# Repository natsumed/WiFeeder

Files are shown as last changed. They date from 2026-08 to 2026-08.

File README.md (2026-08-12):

# WiFeeder v2 — Project README

> **Wireless Automatic Cow Feeding System**  
> NRF24L01+ 2.4 GHz Communication | NUCLEO-L432KC | Raspberry Pi  

> **Status (2026-08-11):** Wiring MVP locked (PCA9685). **NRF VCC = 3.3 V** — Nucleo 5V (~4.8 V) permanently kills PA/LNA (SPI can still look OK). Firmware motor path is I2C PCA9685. Actuator hybrid PCB in [`pcb/`](pcb/). Pi host uses **JSON**. RF over-air still the bring-up gate (need **new** modules after the 5 V damage).

---

## Quick Navigation

| Document | Description |
|---|---|
| [docs/wifeeder-v2-final-plan.md](./docs/wifeeder-v2-final-plan.md) | **Implementation plan** — pins, v1 port, phases, acceptance |
| [ARCHITECTURE.md](./ARCHITECTURE.md) | System architecture, state machines, data flow diagrams |
| [HARDWARE.md](./HARDWARE.md) | Pin mappings, wiring diagrams, power budget |
| [pcb/](./pcb/) | **Actuator hybrid PCB** (KiCad **6.0**) — PCA9685 + bucks on-board; Nucleo/IBT/NRF modules |
| [wiring/](./wiring/) | **Fritzing pack** — bench / no-PCB; `wifeeder-v2.fzz`, GX map |
| [PROTOCOL.md](./PROTOCOL.md) | NRF24L01+ communication protocol specification |
| [SOFTWARE.md](./SOFTWARE.md) | Code architecture, task model, class diagrams |
| [TESTING.md](./TESTING.md) | Test strategy, test cases, validation procedures |
| [DEPLOYMENT.md](./DEPLOYMENT.md) | Build, flash, and deployment instructions |
| [TROUBLESHOOTING.md](./TROUBLESHOOTING.md) | Common problems and solutions |
| [BILL_OF_MATERIALS.md](./BILL_OF_MATERIALS.md) | Complete materials list |

---

## System Overview

```mermaid
graph LR
    CLOUD[" Agpro Cloud"] <-->|"MQTT"| RPI[" Raspberry Pi"]
    RPI <-.->|"NRF24L01+<br/>2.4 GHz"| STM[" NUCLEO-L432KC"]
    STM --> RFID[" RFID Reader"]
    STM --> MOTOR[" Motors (2x)"]
    STM --> HX711[" Load Cell"]
```

WiFeeder v2 is a complete rewrite of the original CAN-bus-based cow feeding system, replacing the problematic wired communication with reliable NRF24L01+ wireless modules.

- **Cow approaches feeder** → RFID tag read
- **Tag sent over NRF24L01+** → Raspberry Pi controller
- **Diet calculation** → Feed command sent back
- **Motors dispense feed** → Encoders verify quantity
- **Consumption reported** → Agpro cloud via MQTT

---

## Repository Structure

```
wifeeder-v2/
├── README.md                          # This file
├── ARCHITECTURE.md                    # System architecture
├── HARDWARE.md                        # Hardware specs
├── PROTOCOL.md                        # Communication protocol
├── SOFTWARE.md                        # Software architecture
├── TESTING.md                         # Test plan
├── DEPLOYMENT.md                      # Deployment guide
├── TROUBLESHOOTING.md                 # Troubleshooting
├── BILL_OF_MATERIALS.md              # Materials list
│
├── stm32/                             # STM32 firmware
│   ├── Core/{Inc,Src}/               # Application code
│   ├── Drivers/                       # HAL & CMSIS
│   ├── Middlewares/                   # FreeRTOS
│   └── Config/                        # RTOS config
│
├── raspberry/                         # RPi host software
│   ├── src/                           # C++ source
│   ├── include/                       # C++ headers
│   ├── config/                        # JSON configs
│   └── tests/                         # GTest tests
│
├── pcb/                               # Actuator hybrid KiCad 8 carrier
├── wiring/                            # Fritzing bench pack
├── docs/                              # Additional docs
├── scripts/                           # Build & deploy
├── tests/                             # Integration tests
└── assets/                            # Images & diagrams
```

---

## Key Differences from v1

| Feature | v1 (CAN) | v2 (NRF24L01+) |
|---|---|---|
| Communication | CAN bus (wired) | NRF24L01+ (wireless) |
| MCU | STM32L486ZGTx | NUCLEO-L432KC |
| Motor Driver | GTK08 | IBT-2 (BTS7960B) |
| Power | Direct 12V | Mini360 DC-DC Buck |
| Protocol | CAN frames (8B) | NRF packets (32B) |
| Database | JSON file (`wifeeder-data.json`) | SQLite (planned) |
| Range | Limited by cable | ~100m wireless |
| Cost per node | ~$15 (CAN parts) | ~$3 (NRF module) |

---

## Quick Start

### Prerequisites

- **Hardware**: NUCLEO-L432KC, NRF24L01+ x2, IBT-2, RFID reader, motors with encoders, Raspberry Pi
- **Software**: STM32CubeIDE, CMake 3.16+, GCC arm-none-eabi, g++ C++20
- **Pi Tools**: spidev / sysfs GPIO, libmosquitto (optional), JSON file DB

### Build STM32 Firmware

```bash
cd stm32
mkdir build && cd build
cmake .. -DCMAKE_TOOLCHAIN_FILE=../cmake/toolchain-arm-none-eabi.cmake
cmake --build . -j$(nproc)
# Flash: Connect Nucleo via USB, drag .bin to virtual drive
```

### Build Raspberry Pi Host

```bash
cd raspberry
mkdir build && cd build
cmake .. -DCMAKE_BUILD_TYPE=Release
cmake --build . -j$(nproc)
# Install: sudo cmake --install .
```

### Configure & Run

```bash
# On Pi:
sudo systemctl enable wifeeder-v2
sudo systemctl start wifeeder-v2

# Monitor:
journalctl -u wifeeder-v2 -f

# Check NRF communication:
sudo candump nrf  # (uses virtual CAN interface to monitor NRF messages)
```

---

## Communication Flow

```mermaid
sequenceDiagram
    participant Cow as 
    participant STM32 as STM32
    participant RPi as RPi
    participant Cloud as  Cloud

    loop Every 5s
        STM32->>RPi: STATUS (heartbeat)
        RPi->>STM32: ACK
    end

    Cow->>STM32: RFID tag read
    STM32->>RPi: RFID_TAG
    RPi->>RPi: Lookup diet
    RPi->>STM32: FEED_CMD (revolutions)
    STM32->>STM32: Dispense feed
    STM32->>RPi: FEED_DONE (actual)
    RPi->>Cloud: Publish via MQTT
```

---

## License

Proprietary — CodinTek © 2024

## Support

For questions or issues, see [TROUBLESHOOTING.md](./TROUBLESHOOTING.md) or contact the development team.

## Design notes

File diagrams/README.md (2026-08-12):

# WiFeeder v2 — Mermaid Diagrams

This directory contains Mermaid `.mmd` files extracted from the project documentation, plus **PLAN-*** diagrams from the implementation plan.

## How to View

### Method 1 — VS Code (Recommended)

1. Open any `.mmd` file
2. VS Code will prompt to install the Mermaid extension — accept it
3. Or press `Ctrl+K V` to open the Mermaid Preview

### Method 2 — Mermaid Live Editor

1. Go to https://mermaid.live/
2. Paste the content of any `.mmd` file
3. See the diagram rendered instantly

### Method 3 — CLI (requires Node.js)

```bash
npm install -g @mermaid-js/mermaid-cli
mmdc -i diagram.mmd -o diagram.png -w 1200
```

## File Index

### Implementation plan (authoritative for pins / port)

| File | Source | Content |
|---|---|---|
| `PLAN-01-system-context.mmd` | docs/wifeeder-v2-final-plan.md | Cloud ↔ Pi ↔ STM32 |
| `PLAN-02-phase-roadmap.mmd` | docs/wifeeder-v2-final-plan.md | Phase gates |
| `PLAN-03-pinmap-l432kc.mmd` | docs/wifeeder-v2-final-plan.md | Locked L432KC pin map |
| `PLAN-04-feed-sequence.mmd` | docs/wifeeder-v2-final-plan.md | RFID → diet → feed → MQTT |
| `PLAN-05-freertos-tasks.mmd` | docs/wifeeder-v2-final-plan.md | Radio / Wifeeder / Cmd / Iwdg |
| `PLAN-06-v1-port-matrix.mmd` | docs/wifeeder-v2-final-plan.md | Port / replace / drop from v1 |
| `PLAN-07-protocol-map.mmd` | docs/wifeeder-v2-final-plan.md | v1 CAN types → v2 NRF types |

### Extracted from docs

| File | Source | Content |
|---|---|---|
| `ARCHITECTURE-01.mmd` … `09` | ARCHITECTURE.md | System overview, flows, topology |
| `HARDWARE-01.mmd` … `09` | HARDWARE.md | Pin maps & wiring (**L432KC-corrected**) |
| `PROTOCOL-01.mmd` … `10` | PROTOCOL.md | Communication protocol |
| `SOFTWARE-01.mmd` … `08` | SOFTWARE.md | Code architecture |
| `TESTING-01.mmd` … `04` | TESTING.md | Test plans |
| `DEPLOYMENT-01.mmd` … `02` | DEPLOYMENT.md | Deployment flows |
| `README-01.mmd` … `02` | README.md | Project overview |
| `TROUBLESHOOTING-01.mmd` … `03` | TROUBLESHOOTING.md | Diagnostics |
| `BILL_OF_MATERIALS-01.mmd` … `03` | BILL_OF_MATERIALS.md | Hardware diagrams |

> **Pin authority:** Prefer `PLAN-03-pinmap-l432kc.mmd` and [`docs/wifeeder-v2-final-plan.md`](../docs/wifeeder-v2-final-plan.md) §2 over any older diagram that cites PB8–PB11, PC0/PC1, TIM3/TIM4, or PA6 as NRF MISO.

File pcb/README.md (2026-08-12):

# WiFeeder actuator carrier (hybrid, spin 1)

KiCad **6.0** project (matches this machine): [`wifeeder-actuator.kicad_pro`](wifeeder-actuator.kicad_pro)

Replaces the Fritzing breadboard, PCA9685 breakout, Mini360, and jumper harness.
Firmware pins are unchanged — see [`../stm32/Core/Inc/board.h`](../stm32/Core/Inc/board.h) and
[`../wiring/CONNECTOR_MAP.md`](../wiring/CONNECTOR_MAP.md).

| On this PCB | Plug-in modules | Off-board |
|---|---|---|
| PCA9685 + passives | NUCLEO-L432KC | Raspberry Pi + NRF |
| Fixed 5 V + 3.3 V bucks | IBT-2 (BTS7960) | PN01007BRKT + GTS06 |
| Enc / I2C pull-ups, fuse, TVS, P-FET | NRF24 + AM1117 (2×4) | 12 V pack |
| Screw / JST connectors | Mini360 **DNP fallback only** | — |

**Do not** chip-down STM32, BTS7960, or nRF24 on this spin.

## Open / regenerate

```bash
# Open in KiCad 6.0 (installed as /usr/bin/kicad)
kicad pcb/wifeeder-actuator.kicad_pro

# After open: PCB editor → B (fill zones) → Inspect → Design Rules Checker
# Schematic: Inspect → Electrical Rules Checker

# Regenerate schematic + placement (no copper — does NOT route)
python3 pcb/tools/generate_project.py
python3 pcb/tools/route_pcb.py      # power + signal routing
python3 pcb/tools/verify_pcb.py     # KiCad connectivity (unconnected must be 0)
python3 pcb/tools/export_fab.py     # zone fill + gerbers
python3 pcb/tools/audit_pcb.py      # pad-to-trace check
```

Fritzing remains the **no-PCB bench** pack under [`../wiring/`](../wiring/).

## Power (read before first apply)

1. No modules seated. Apply 12 V to **TB1**. Measure **TP5V ≈ 5.00 V**, **TP3V3 ≈ 3.30 V**.
2. Seat Nucleo with **USB unplugged** (carrier feeds **3V3 → Nucleo 3V3**).
3. Seat NRF adapter: **VCC is 5 V** (not 3.3 V).
4. Seat IBT-2. Wire **TB2** (12V_SAFE / GND) to IBT **B+ / B−** with short 16 AWG (module has no underside power pins). Motor: IBT **M+/M−** and/or **TB3**.
5. Encoder on **TB4** (5 V VCC, 3.3 V pull-ups on A/B).

Mini360 (`J_MINI`) is **do not populate** unless the AP63203 is omitted and `SJ_MINI` is closed.

## Sheets

| File | Contents |
|---|---|
| `wifeeder-actuator.kicad_sch` | Root / hierarchy |
| `power.kicad_sch` | 12 V protect, 5 V / 3.3 V bucks, Mini360 DNP |
| `mcu.kicad_sch` | Nucleo-32 sockets, NRF, encoder, RFID/HX711 DNP |
| `pca.kicad_sch` | PCA9685 chip-down |
| `ibt.kicad_sch` | IBT-2 logic + power screws |
| `connectors.kicad_sch` | Mechanical notes / mounting |

Pinouts: [`CONNECTORS.md`](CONNECTORS.md).

## Fab

- 2-layer, 1.6 mm, 2 oz Cu preferred, 100×150 mm, ENIG or HASL
- Gerbers: [`fab/`](fab/)
- Keepout: no 12 V under NRF antenna (top-right)

## Bring-up

1. Rails only (above)
2. Nucleo LED blink
3. PCA ACK `0x40`
4. [`../tests/04-motor`](../tests/04-motor/)
5. NRF tests 10 then 09, CH **76**, antennas, ≥10 cm
6. Encoder **2400** counts/rev

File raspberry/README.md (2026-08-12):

# WiFeeder v2 — Raspberry Pi Host

Host controller for WiFeeder v2: NRF24L01+ link to STM32 actuators, diet calculation, JSON database, and MQTT uplink.

Station serial number: **WCN-A100-0001X**

## Features

- 32-byte NRF protocol (`0x01`–`0x08`) with CRC-8 poly `0x07` (matches STM32)
- `nrf_link` API (init/start/stop/sendto/recv) modeled on v1 `walink`
- LINEAR_FORCED diet engine ported from v1 `diet.cpp`
- JSON file database (`wifeeder-data.json`) with mutex
- MQTT via libmosquittopp (optional stub without it)
- Desktop Linux build uses NRF stub (logs packets, no SPI)

## Dependencies

**Required**

- CMake ≥ 3.16, C++17 compiler, pthread

**Optional**

- `jsoncpp` — used when found; otherwise embedded `min_json`
- `libmosquittopp` — real MQTT; otherwise stub logs to stdout
- `libgtest-dev` — GoogleTest runner for `test_diet`

On Raspberry Pi OS:

```bash
sudo apt update
sudo apt install -y cmake g++ libjsoncpp-dev libmosquittopp-dev
```

## Build

### Desktop (stub NRF, diet unit tests)

```bash
cd raspberry
cmake -B build -DWIFEEDER_BUILD_TESTS=ON
cmake --build build
ctest --test-dir build --output-on-failure
```

### Raspberry Pi (SPI + GPIO)

Enable SPI and reboot:

```bash
sudo raspi-config   # Interface Options → SPI → Enable
# or:
echo dtparam=spi=on | sudo tee -a /boot/config.txt
sudo reboot
```

Build with Pi defines:

```bash
cd raspberry
cmake -B build -DRASPBERRY_PI=ON
cmake --build build
```

## Run

Copy seed data (first run):

```bash
cp config/wifeeder-data.json ./wifeeder-data.json
# or set WIFEEDER_DATA=/etc/wifeeder-data.json
```

Start host:

```bash
./build/wifeeder_host
```

Environment variables:

| Variable | Default | Description |
|---|---|---|
| `WIFEEDER_DATA` | `./wifeeder-data.json` | Animal/diet JSON database path |

## Wiring (NRF24L01+ → Raspberry Pi)

| NRF pin | Pi connection |
|---|---|
| VCC | 3.3V (use adapter with regulator) |
| GND | GND |
| CE | GPIO25 (BCM) |
| CSN | SPI0 CE0 |
| SCK | SCLK (pin 23) |
| MOSI | MOSI (pin 19) |
| MISO | MISO (pin 21) |
| IRQ | not connected |

SPI device: `/dev/spidev0.0`

Radio settings match STM32 and `PROTOCOL.md`:

- Channel 76 (2.476 GHz)
- 1 Mbps, 32-byte payload
- Address `0xE7E7E7E7E7`

## Thread model

1. **NRF RX thread** (`nrf_link`) — receives packets, auto-ACK
2. **Feed thread** — `RFID_TAG` → diet `get_portion` → `FEED_CMD`; `FEED_DONE` → log + MQTT
3. **Status thread** — `STATUS` heartbeat + 5 min offline detection
4. **Daily reset thread** — ~23:50 daily_reset for all animals

## Message flow

See [PROTOCOL.md](../PROTOCOL.md) and [docs/wifeeder-v2-final-plan.md](../docs/wifeeder-v2-final-plan.md).

```
STM32 --RFID_TAG(0x02)--> Host --lookup DB--> diet.get_portion()
Host --FEED_CMD(0x03)--> STM32 --dispense--> FEED_DONE(0x04) --> Host log + MQTT
STM32 --STATUS(0x01)--> Host (every 5s heartbeat)
```

## Unit tests

```bash
./build/test_diet
```

Tests cover portion calculation, grams↔revs conversion (16 rev calibration reference), and `daily_reset` without hardware.

## License

Portions derived from WiFeeder v1 (CodinTek / Mohamed HNEZLI).

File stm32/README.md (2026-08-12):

# STM32 firmware (NUCLEO-L432KC)

Production firmware entry: `Core/Src/main.c` → `wifeeder_init()` / `wifeeder_poll()`.

## Drivers

| Module | Role |
|---|---|
| `nrf24l01` | Bit-bang SPI (PA4 CSN, PB1 MISO) |
| `protocol` / `crc8` | 32-byte NRF packets |
| `rfid` | USART2 RX PA3, `$A0112OKD` frames |
| `motor` | IBT-2 TIM1/TIM16 PWM |
| `encoder` | TIM2 PA0/PA1 |
| `hx711` | PB4/PB5 |
| `flash_int` | Device ID (RAM + flash read) |
| `wifeeder` | Feed loop (STATUS / RFID / FEED_CMD / FEED_DONE) |

FreeRTOS sources are vendored under `Middlewares/Third_Party/FreeRTOS/` (task split later).

## Build

```bash
docker run --rm --user root \
  -v "$PWD:/workspace" -v /home/luceor/Desktop/wifeeder:/wifeeder \
  wifeeder-dev bash -c '
  export PATH=/opt/arm-gcc/bin:$PATH
  cd /workspace/stm32 && mkdir -p build_prod && cd build_prod
  cmake .. -DCMAKE_TOOLCHAIN_FILE=/wifeeder/cmake/toolchain-arm-none-eabi.cmake
  cmake --build . -j$(nproc)
'

# Flash
cp build_prod/wifeeder_v2_mcu.bin /media/$USER/NODE_L432KC/
```

Hardware bring-up tests: see [`../tests/README.md`](../tests/README.md).

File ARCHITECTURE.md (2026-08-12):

# WiFeeder v2 — Architecture Overview

> **Version**: 2.0.0  
> **Communication**: NRF24L01+ 2.4 GHz Wireless  
> **MCU**: STM32 NUCLEO-L432KC  
> **Host**: Raspberry Pi 3B+/4  

---

## Table of Contents

1. [System Overview](#system-overview)
2. [Component Architecture](#component-architecture)
3. [Data Flow](#data-flow)
4. [Network Topology](#network-topology)
5. [Power Architecture](#power-architecture)
6. [State Machines](#state-machines)
7. [Directory Structure](#directory-structure)

---

## System Overview

```mermaid
graph TB
    subgraph Cloud[" Agpro Cloud"]
        MQTT_BROKER["MQTT Broker<br/>Cloud Backend"]
        WEB_DASH["Web Dashboard<br/>Farmer Interface"]
    end

    subgraph RPi[" Raspberry Pi Controller"]
        MQTT_CLIENT["MQTT Client<br/>(Mosquitto)"]
        DIET_ENGINE["Diet Engine<br/>(C++20)"]
        DB["SQLite<br/>Database"]
        WEB_SRV["Web Server<br/>(Optional)"]
        NRF_RPI["NRF24L01+<br/>SPI0 Module"]

        MQTT_CLIENT <--> |"JSON/TLS"| MQTT_BROKER
        MQTT_CLIENT --> DIET_ENGINE
        DIET_ENGINE --> DB
        DIET_ENGINE --> NRF_RPI
        WEB_SRV --> DB
    end

    subgraph STM32[" NUCLEO-L432KC Actuator"]
        NRF_STM32["NRF24L01+<br/>SPI1 Module"]
        MAIN_LOOP["Main Control<br/>Loop"]
        RFID["RFID Reader<br/>125kHz/EM"]
        MOTOR["IBT-2 Motor<br/>Driver"]
        ENCODER["Quadrature<br/>Encoders"]
        HX711["HX711 Load<br/>Cell (Opt.)"]
        CLI["Debug CLI<br/>UART2"]

        NRF_STM32 --> MAIN_LOOP
        MAIN_LOOP --> RFID
        MAIN_LOOP --> MOTOR
        MAIN_LOOP --> ENCODER
        MAIN_LOOP --> HX711
        MAIN_LOOP --> CLI
    end

    NRF_RPI <-.-> |"2.4GHz"| NRF_STM32
    POWER[" 12V Battery<br/>+ Mini360 Buck"] --> STM32

    style Cloud fill:#e1f5fe,stroke:#01579b
    style RPi fill:#e8f5e9,stroke:#1b5e20
    style STM32 fill:#fff3e0,stroke:#e65100
    style POWER fill:#fce4ec,stroke:#880e4f
```

---

## Component Architecture

```mermaid
graph LR
    subgraph Pi["Raspberry Pi"]
        direction TB
        A1["NRF24L01+ Driver<br/>(C++)"] --> A2["Protocol Layer<br/>(msg pack/unpack)"]
        A2 --> A3["Message Router"]
        A3 --> A4["Diet Engine"]
        A3 --> A5["MQTT Client"]
        A4 --> A6["SQLite DB"]
        A5 --> A7["Mosquitto"]
    end

    subgraph STM32["NUCLEO-L432KC"]
        direction TB
        B1["NRF24L01+ Driver<br/>(C)"]
        B1 --> B2["Protocol Layer<br/>(msg pack/unpack)"]
        B2 --> B3["Main Task<br/>(FreeRTOS)"]
        B3 --> B4["RFID Task"]
        B3 --> B5["Motor Task"]
        B3 --> B6["Sensor Task"]
        B3 --> B7["Watchdog Task"]
        B4 --> B8["UART2"]
        B5 --> B9["PWM + GPIO"]
        B6 --> B10["HX711 SPI"]
    end

    A1 <-.-> |"2.4 GHz"| B1
```

---

## Data Flow

### End-to-End Feeding Cycle

```mermaid
sequenceDiagram
    participant Cow as  Cow
    participant RFID as RFID Reader
    participant STM32 as STM32 MCU
    participant NRF_S as NRF24L01 (STM)
    participant NRF_P as NRF24L01 (RPi)
    participant RPi as Raspberry Pi
    participant DB as SQLite DB
    participant MQTT as Agpro Cloud

    Cow->>RFID: Approaches feeder
    RFID->>STM32: Tag detected (125kHz)
    STM32->>NRF_S: Send RFID_TAG (msg ID=0x02)
    NRF_S->>NRF_P: 2.4GHz packet
    NRF_P->>RPi: RFID_TAG received
    RPi->>DB: Lookup animal (RFID)
    DB->>RPi: Diet data found
    RPi->>RPi: Calculate portion
    RPi->>NRF_P: Send FEED_CMD (msg ID=0x03)
    NRF_P->>NRF_S: 2.4GHz packet
    NRF_S->>STM32: FEED_CMD received
    STM32->>STM32: Start motors + encoders
    Note over STM32: Dispensing feed...
    STM32->>NRF_S: Send FEED_DONE (msg ID=0x04)
    NRF_S->>NRF_P: 2.4GHz packet
    NRF_P->>RPi: FEED_DONE received
    RPi->>DB: Update consumption
    RPi->>MQTT: Publish feed event
    MQTT->>RPi: Acknowledge
```

### Heartbeat & Status Flow

```mermaid
sequenceDiagram
    participant STM32 as STM32 MCU
    participant NRF_S as NRF24L01 (STM)
    participant NRF_P as NRF24L01 (RPi)
    participant RPi as Raspberry Pi

    loop Every 5 seconds
        STM32->>NRF_S: Send STATUS (msg ID=0x01)
        NRF_S->>NRF_P: 2.4GHz packet + auto-ACK
        NRF_P->>RPi: STATUS received
        RPi->>NRF_P: Send ACK (msg ID=0x07)
        NRF_P->>NRF_S: 2.4GHz packet + auto-ACK
        NRF_S->>STM32: ACK received
        Note over STM32: Update connection status
    end
```

---

## Network Topology

```mermaid
graph TB
    subgraph Farm[" Farm Layout"]
        subgraph Station1["Station 1"]
            RPi1["Raspberry Pi<br/>Controller #1"]
            STM1_1["Actuator #1<br/>NUCLEO-L432KC"]
            STM1_2["Actuator #2<br/>NUCLEO-L432KC"]
            STM1_3["Actuator #3<br/>NUCLEO-L432KC"]
            RPi1 <-.-> |"NRF24L01+"| STM1_1
            RPi1 <-.-> |"NRF24L01+"| STM1_2
            RPi1 <-.-> |"NRF24L01+"| STM1_3
        end

        subgraph Station2["Station 2"]
            RPi2["Raspberry Pi<br/>Controller #2"]
            STM2_1["Actuator #1<br/>NUCLEO-L432KC"]
            STM2_2["Actuator #2<br/>NUCLEO-L432KC"]
            RPi2 <-.-> |"NRF24L01+"| STM2_1
            RPi2 <-.-> |"NRF24L01+"| STM2_2
        end
    end

    RPi1 --> |"MQTT"| Cloud[" Agpro Cloud"]
    RPi2 --> |"MQTT"| Cloud
```

---

## Power Architecture

```mermaid
graph TB
    BAT[" 12V Battery<br/>or Adapter"] -->|"12V DC"| IBT["IBT-2 Motor Driver<br/>(5-27V tolerant)"]
    BAT -->|"12V DC"| MINI["Mini360 DC-DC<br/>Buck Converter"]
    MINI -->|"3.3V / 3A"| STM32["NUCLEO-L432KC<br/>(3.3V)"]
    MINI -->|"3.3V / 3A"| NRF["NRF24L01+ Module<br/>(3.3V max)"]
    MINI -->|"3.3V / 3A"| RFID_READER["RFID Reader<br/>(3.3V/5V)"]
    IBT -->|"12V PWM"| MOTOR1["Motor 1<br/>DC Brushed"]
    IBT -->|"12V PWM"| MOTOR2["Motor 2<br/>DC Brushed"]
    IBT -->|"5V out"| ENCODER["Encoder<br/>Power"]
    STM32 -->|"5V USB"| USB["USB Debug<br/>Serial Console"]

    style BAT fill:#fce4ec,stroke:#880e4f
    style MINI fill:#e8eaf6,stroke:#283593
    style IBT fill:#fff3e0,stroke:#e65100
    style STM32 fill:#e8f5e9,stroke:#1b5e20
```

---

## STM32 State Machine

```mermaid
stateDiagram-v2
    [*] --> INIT: Power On
    INIT --> CONFIG_READ: Boot
    CONFIG_READ --> RADIO_INIT: Read config
    RADIO_INIT --> IDLE: NRF24L01+ ready

    IDLE --> HEARTBEAT: Timer (5s)
    HEARTBEAT --> WAIT_ACK: Send STATUS
    WAIT_ACK --> IDLE: ACK received
    WAIT_ACK --> RETRY: No ACK (3 retries)
    RETRY --> IDLE: After retry
    RETRY --> ERROR: After max retries
    ERROR --> IDLE: Reconnect

    IDLE --> TAG_READ: RFID detected
    TAG_READ --> SEND_TAG: Tag valid
    SEND_TAG --> WAIT_CMD: RFID_TAG sent

    WAIT_CMD --> START_FEED: FEED_CMD received
    WAIT_CMD --> IDLE: Timeout (no command)
    START_FEED --> FEEDING: Motors running
    FEEDING --> FEED_DONE: Encoders done
    FEED_DONE --> IDLE: FEED_DONE sent

    IDLE --> WEIGHING: Weight requested
    WEIGHING --> IDLE: WEIGHT sent
```

---

## Message Routing (Raspberry Pi)

```mermaid
stateDiagram-v2
    [*] --> LISTENING: NRF24L01+ initialized

    LISTENING --> PARSE: Packet received
    PARSE --> CRC_CHECK: Parse header
    CRC_CHECK --> ROUTE: CRC valid
    CRC_CHECK --> LISTENING: CRC invalid (discard)

    ROUTE --> STATUS_HANDLER: MsgType=0x01
    ROUTE --> RFID_HANDLER: MsgType=0x02
    ROUTE --> FEEDBACK_HANDLER: MsgType=0x04
    ROUTE --> WEIGHT_HANDLER: MsgType=0x05
    ROUTE --> ERROR_HANDLER: MsgType=0x08

    STATUS_HANDLER --> UPDATE_HEARTBEAT: Update timestamp
    UPDATE_HEARTBEAT --> SEND_ACK: Send ACK (0x07)
    SEND_ACK --> LISTENING

    RFID_HANDLER --> LOOKUP_DB: Lookup animal
    LOOKUP_DB --> CALC_PORTION: Animal found
    LOOKUP_DB --> LISTENING: Unknown animal
    CALC_PORTION --> SEND_CMD: Send FEED_CMD (0x03)
    SEND_CMD --> LISTENING

    FEEDBACK_HANDLER --> UPDATE_DB: Update consumption
    UPDATE_DB --> PUBLISH_MQTT: Publish to cloud
    PUBLISH_MQTT --> LISTENING

    WEIGHT_HANDLER --> STORE_WEIGHT: Store in DB
    STORE_WEIGHT --> LISTENING

    ERROR_HANDLER --> LOG_ERROR: Log to syslog
    LOG_ERROR --> LISTENING
```

---

## Directory Structure

```
wifeeder-v2/
├── README.md                          # Project overview
├── ARCHITECTURE.md                    # This file
├── HARDWARE.md                        # Hardware specs & wiring
├── PROTOCOL.md                        # NRF24L01+ protocol
├── SOFTWARE.md                        # Software architecture
├── TESTING.md                         # Test plan
├── DEPLOYMENT.md                      # Deployment guide
├── TROUBLESHOOTING.md                 # Common issues
├── BILL_OF_MATERIALS.md              # Materials list
│
├── stm32/                             # STM32 firmware
│   ├── Core/
│   │   ├── Inc/                       # Headers
│   │   └── Src/                       # Source
│   ├── Drivers/                       # HAL & CMSIS
│   ├── Middlewares/                   # FreeRTOS
│   └── Config/                        # FreeRTOS config
│
├── raspberry/                         # Raspberry Pi controller
│   ├── src/                           # C++ source
│   ├── include/                       # C++ headers
│   ├── config/                        # JSON configs
│   └── tests/                         # GTest tests
│
├── docs/                              # Additional docs
├── scripts/                           # Build & deploy scripts
├── tests/                             # Integration tests
│   ├── unit/                          # Unit tests
│   ├── integration/                   # Integration tests
│   └── system/                        # System tests
└── assets/                            # Images & diagrams
```

---

## Key Design Decisions

| Decision | Rationale |
|---|---|
| NRF24L01+ over CAN | Eliminates wiring issues; cheaper modules |
| NUCLEO-L432KC over L486 | Smaller, cheaper, sufficient peripherals |
| IBT-2 over GTK08 | BTS7960B more robust; better current handling |
| Mini360 buck converter | Efficient 12V→3.3V; adjustable; 3A capacity |
| FreeRTOS (kept) | Real-time motor/encoder control needs |
| SQLite (new on RPi) | Better structured queries vs JSON file |
| 1 Mbps NRF data rate | Best balance of range/speed |

---

## Comparison: v1 vs v2

```mermaid
graph LR
    subgraph V1["v1 (CAN Bus)"]
        direction TB
        C1[" CAN bus wiring<br/>problems for years"]
        C2[" Termination<br/>issues"]
        C3[" Wired connections<br/>limit placement"]
        C4[" Complex<br/>debugging"]
    end

    subgraph V2["v2 (NRF24L01+)"]
        direction TB
        D1[" No wiring<br/>wireless comms"]
        D2[" Auto-retry<br/>reliable delivery"]
        D3[" Flexible<br/>actuator placement"]
        D4[" Simple SPI<br/>easy to debug"]
    end

    V1 --> V2
    style V1 fill:#ffcdd2,stroke:#c62828
    style V2 fill:#c8e6c9,stroke:#2e7d32
```

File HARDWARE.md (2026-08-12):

# WiFeeder v2 — Hardware Specifications & Wiring

> **MCU**: NUCLEO-L432KC (STM32L432KCU6, UFQFPN32)  
> **Motor Driver**: IBT-2 (BTS7960B) via **PCA9685** PWM  
> **Power**: Mini360 DC-DC Buck Converter  
> **Wireless**: NRF24L01+ 2.4 GHz (bit-bang SPI)  
> **Authority**: [`wiring/CONNECTOR_MAP.md`](wiring/CONNECTOR_MAP.md) + [`stm32/Core/Inc/board.h`](stm32/Core/Inc/board.h)

**Package limits:** No PB8–PB11, PC0–PC13, TIM3, or TIM4. LED = **PB3**. **PA6 shorted** — NRF MISO = **PB1**. **One jumper per Nucleo pin**. Bench logic power is **Nucleo USB** (3V3→X, 5V→Z). **Do not** feed Mini360 OUT into Nucleo 3V3 until the pot is **3.30 V**. **NRF VCC = 3.3 V** (never Nucleo 5V).

---

## 1. NUCLEO-L432KC Pin Allocation (MVP)

Diagram: [`diagrams/HARDWARE-01.mmd`](diagrams/HARDWARE-01.mmd).

| Pin | Mode | Function | Connected To |
|-----|---|---|---|
| PA0 | AF1 TIM2_CH1 | Encoder 1A | Enc **green** → BB col 40 |
| PA1 | AF1 TIM2_CH2 | Encoder 1B | Enc **white** → BB col 41 |
| PA2 | AF8 LPUART1 | Debug VCP | ST-Link |
| PA3 | USART2_RX | RFID (deferred) | — |
| PA4 | GPIO Out | NRF CSN | NRF CSN |
| PA5 | GPIO Out | NRF SCK | NRF SCK |
| PA6 | — | **Do not use** | Shorted |
| PA7 | GPIO Out | NRF MOSI | NRF MOSI |
| PA8 / PA9 | — | Free (legacy TIM1) | — |
| PB0 | GPIO Out | NRF CE | NRF CE |
| PB1 | GPIO In PU | NRF MISO | NRF MISO |
| PB3 | GPIO Out | LED | LD3 |
| PB4 / PB5 | — | HX711 (deferred) | — |
| **PB6** | I2C SCL | **PCA9685 SCL** | PCA SCL (D5) |
| **PB7** | I2C SDA | **PCA9685 SDA** | PCA SDA (D4) |

**MVP:** PCA9685 + 1 motor + Enc1 (600 P/R) + NRF + LED. RFID / HX711 / Motor2 deferred.

### board.h ↔ wiring checklist

| `board.h` | Wiring |
|---|---|
| `BOARD_NRF_*` | PA5/7, PB1, PA4, PB0 |
| `BOARD_I2C_SCL/SDA` | PB6 / PB7 |
| `BOARD_PCA_CH_RPWM/LPWM` | PWM0 / PWM1 |
| `BOARD_ENCODER_PPR` | **600** |
| `BOARD_ENCODER_COUNTS_PER_REV` | **2400** (TIM2 ×4) |

---

## 2. NRF24L01+ Wiring

STM: PA5 SCK, PB1 MISO, PA7 MOSI, PA4 CSN, PB0 CE. **VCC = 3.3 V** (Buck / BB X). Channel **76**.

Pi: SPI0 + GPIO25 CE; **VCC = pin 1 (3.3 V)**.

**Never** put Nucleo/Pi **5 V** on module VCC. That is ~4.8 V; abs max is 3.6 V. It destroys PA/LNA while SPI still looks healthy.

---

## 3. Motor path (PCA9685 → IBT-2)

```mermaid
graph TB
    subgraph PCA["PCA9685"]
        PWM0["PWM0"]
        PWM1["PWM1"]
    end
    subgraph IBT["IBT-2 Motor1"]
        RPWM["RPWM"]
        LPWM["LPWM"]
        EN["R_EN/L_EN → Buck 3V3"]
        MOUT["M+/M- → GX-2 → Motor"]
    end
    PWM0 --> RPWM
    PWM1 --> LPWM
```

- OE → Buck GND (outputs enabled)
- Forward: RPWM=PWM, LPWM=0 · Reverse: RPWM=0, LPWM=PWM
- PCA PWM ~1 kHz (IBT-tolerant)
- Legacy TIM1/TIM16 on PA8/PB6 **retired** for MVP

Fritzing: [`wiring/blocks/03-motor.fzz`](wiring/blocks/03-motor.fzz)

---

## 4. Encoder Wiring

**GTS06-OC-RA600A-2M** (600 P/R, NPN OC) as a **factory 4-wire assembly** (encoder + cable + plug). Do not wire a separate GX-4 and encoder body.

Pigtail is **2× red + 2× black** — color is **not** VCC/GND/A/B. Use molded pin numbers + the meter procedure in [`wiring/CONNECTOR_MAP.md`](wiring/CONNECTOR_MAP.md). Then: VCC → BB **Z**, GND → **Y**, A → col **40** / PA0, B → col **41** / PA1.

Pull-ups **4.7 kΩ on A/B → 3V3** (not 5 V; not stacked on Nucleo A0/A1). TIM2 ×4 → **2400 counts/rev**. Swap A/B if direction is inverted.

---

## 5. RFID / HX711

Deferred in MVP Fritzing. Drivers exist; gated with `WIFEEDER_MVP` in firmware. Pins reserved: PA3 RFID, PB4/PB5 HX711.

---

## 6. Complete Wiring

**Production path:** hybrid carrier PCB — [`pcb/README.md`](pcb/README.md), pinouts [`pcb/CONNECTORS.md`](pcb/CONNECTORS.md).  
On-board: PCA9685, fixed 5 V / 3.3 V bucks, fuse, TVS, P-FET, pull-ups. Modules: Nucleo-32, IBT-2, NRF+AM1117.  
**Bench / no-PCB:** [`wiring/wifeeder-v2.fzz`](wiring/wifeeder-v2.fzz) · blocks in [`wiring/blocks/`](wiring/blocks/).

```mermaid
graph TB
    BAT["12V Battery"] -->|"12V fuse P-FET"| IBT["IBT-2"]
    BAT -->|"12V Mini360 IN only"| BUCK["Mini360 — OUT off X until 3.30V"]
    USB["Nucleo USB"] -->|"3V3 → X"| STM32["NUCLEO-L432KC"]
    USB -->|"3V3 → X"| PCA["PCA9685"]
    STM32 -->|"I2C PB6/PB7"| PCA
    PCA -->|"PWM0/1"| IBT
    USB -->|"3V3 → X"| NRF["NRF VCC"]
    USB -->|"5V → Z"| IBT
    USB -->|"5V → Z"| ENC1["Enc 4-wire"]
    IBT -->|"GX-2"| MOTOR1["PN01007BRKT"]
    ENC1 -->|"A / B after meter ID"| STM32
    NRF <-.->|"CH76"| NRF_PI["NRF on Pi"]
```

---

## 7. Power Budget

| Component | Voltage | Notes |
|---|---|---|
| Nucleo | 3.3V | Carrier AP63203 (USB unplugged) |
| PCA9685 | 3.3V | On-carrier |
| NRF | **3.3V** | Buck / BB X — never Nucleo 5V |
| IBT logic | 5V | Carrier 5 V rail |
| Motor | 12V | Battery via fuse / P-FET → IBT B+ |

---

## 8. NUCLEO-L432KC Key Specs

| Parameter | Value |
|---|---|
| Core | Cortex-M4 |
| Flash / SRAM | 256 KB / 64 KB |
| Timers (MVP) | TIM2 Enc1; SysTick |
| PWM | External PCA9685 |
| Debug | SWD + ST-Link |

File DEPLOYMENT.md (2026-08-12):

# WiFeeder v2 — Deployment Guide

---

## Table of Contents

1. [STM32 Firmware Deployment](#stm32-firmware-deployment)
2. [Raspberry Pi Deployment](#raspberry-pi-deployment)
3. [NRF24L01+ Setup](#nrf24l01-setup)
4. [Systemd Service Configuration](#systemd-service-configuration)
5. [MQTT Configuration](#mqtt-configuration)
6. [Docker Deployment (Optional)](#docker-deployment-optional)

---

## 1. STM32 Firmware Deployment

### 1.1 Prerequisites

```bash
# Install ARM GCC toolchain
sudo apt update
sudo apt install gcc-arm-none-eabi binutils-arm-none-eabi
```

### 1.2 Build & Flash

```mermaid
sequenceDiagram
    participant Dev as Developer PC
    participant STM32 as NUCLEO-L432KC

    Dev->>Dev: Clone repository
    Dev->>Dev: cd stm32 && mkdir build && cd build
    Dev->>Dev: cmake .. -DTOOLCHAIN=arm-none-eabi
    Dev->>Dev: cmake --build . -j$(nproc)
    Dev->>Dev: Check build output
    Note over Dev: wifeeder_mcu.bin created
    Dev->>STM32: Copy .bin to NUCLEO drive
    Dev->>STM32: Press RESET button
    STM32->>STM32: Boot new firmware
    Dev->>STM32: Open serial terminal (115200 baud)
    Note over Dev,STM32: Verify boot messages
```

### 1.3 CLI Configuration

After flashing, configure the actuator via serial terminal:

```text
# Connect to NUCLEO serial at 115200 baud
screen /dev/ttyACM0 115200

# Set device ID (1-254)
flash-device-id 1

# Set machine type
flash-device-type 3

# Verify
get-id
get-type

# Set NRF channel (optional, default 76)
set-nrf-channel 76

# Reset to apply
reset
```

---

## 2. Raspberry Pi Deployment

### 2.1 OS Setup

```bash
# On Raspberry Pi (fresh Raspbian/Ubuntu)
sudo apt update && sudo apt upgrade -y

# Enable SPI interface
sudo raspi-config
# → Interface Options → SPI → Enable

# Install dependencies
sudo apt install -y \
    cmake \
    build-essential \
    g++ \
    libmosquitto-dev \
    libsqlite3-dev \
    libwiringpi-dev \
    git

# Enable SPI
sudo sed -i 's/#dtparam=spi=on/dtparam=spi=on/' /boot/config.txt
sudo reboot
```

### 2.2 Build Application

```bash
# Clone repository
git clone <repo-url> /opt/wifeeder-v2

# Build
cd /opt/wifeeder-v2/raspberry
mkdir build && cd build
cmake .. -DCMAKE_BUILD_TYPE=Release
cmake --build . -j$(nproc)

# Install
sudo cmake --install .
sudo cp config/config.json /etc/wifeeder-v2/config.json
```

### 2.3 Database Setup

```bash
# Create database directory
sudo mkdir -p /etc/wifeeder-v2

# Initialize SQLite database
sudo sqlite3 /etc/wifeeder-v2/wifeeder.db < /opt/wifeeder-v2/raspberry/config/schema.sql

# Set permissions
sudo chown -R pi:pi /etc/wifeeder-v2
```

---

## 3. NRF24L01+ Setup

### 3.1 Wiring Verification

```mermaid
graph TB
    subgraph Pi["Raspberry Pi"]
        P1["Pin 19 (GPIO10 MOSI)"]
        P2["Pin 21 (GPIO9 MISO)"]
        P3["Pin 23 (GPIO11 SCLK)"]
        P4["Pin 24 (GPIO8 CE0)"]
        P5["Pin 22 (GPIO25 CE)"]
        P6["Pin 18 (GPIO24 IRQ)"]
        P7["Pin 1  (3.3V)"]
        P8["Pin 6  (GND)"]
    end

    subgraph NRF["NRF24L01+"]
        N1["MOSI"]
        N2["MISO"]
        N3["SCK"]
        N4["CSN"]
        N5["CE"]
        N6["IRQ"]
        N7["VCC"]
        N8["GND"]
    end

    P1 --> N1
    P2 --> N2
    P3 --> N3
    P4 --> N4
    P5 --> N5
    N6 --> P6
    P7 --> N7
    P8 --> N8
```

### 3.2 NRF Test

```bash
# Build and run NRF test tool
cd /opt/wifeeder-v2/raspberry
g++ -o nrf_test tools/nrf_test.cpp src/nrf24l01.cpp \
    -lwiringPi -Iinclude
sudo ./nrf_test

# Expected output:
# NRF24L01+ detected: OK
# SPI communication: OK
# TX test: PASS
# RX test: PASS
```

---

## 4. Systemd Service Configuration

### 4.1 Service File

```bash
sudo tee /etc/systemd/system/wifeeder-v2.service << 'EOF'
[Unit]
Description=WiFeeder v2 Controller Service
Documentation=https://github.com/codintek/wifeeder-v2
After=network.target mosquitto.service
Wants=mosquitto.service

[Service]
Type=simple
User=pi
Group=pi
WorkingDirectory=/opt/wifeeder-v2
ExecStartPre=/bin/sleep 5
ExecStart=/opt/wifeeder-v2/raspberry/build/wifeeder_host
Restart=always
RestartSec=10
StartLimitInterval=60
StartLimitBurst=5

# Logging
StandardOutput=journal
StandardError=journal
SyslogIdentifier=wifeeder-v2

# Security hardening
NoNewPrivileges=yes
PrivateTmp=yes
ProtectSystem=full
ProtectHome=yes
ReadWritePaths=/etc/wifeeder-v2

[Install]
WantedBy=multi-user.target
EOF
```

### 4.2 Enable & Start

```bash
sudo systemctl daemon-reload
sudo systemctl enable wifeeder-v2
sudo systemctl start wifeeder-v2

# Check status
sudo systemctl status wifeeder-v2

# View logs
sudo journalctl -u wifeeder-v2 -f

# View last 100 lines
sudo journalctl -u wifeeder-v2 -n 100 --no-pager
```

---

## 5. MQTT Configuration

### 5.1 Mosquitto Setup

```bash
# Install
sudo apt install mosquitto mosquitto-clients -y

# Configure
sudo tee /etc/mosquitto/conf.d/wifeeder.conf << 'EOF'
listener 1883
allow_anonymous false
password_file /etc/mosquitto/passwd

# Logging
log_dest file /var/log/mosquitto/mosquitto.log
log_type all
EOF

# Set password
sudo mosquitto_passwd -c /etc/mosquitto/passwd client2
# Enter: wifeeder@agTEK.2020_2_mqtt

sudo systemctl restart mosquitto
```

### 5.2 Test MQTT

```bash
# Subscribe to all topics
mosquitto_sub -h localhost -u client2 -P 'wifeeder@agTEK.2020_2_mqtt' \
    -t 'WCN-A100-0001X/#' -v

# In another terminal, publish test message
mosquitto_pub -h localhost -u client2 -P 'wifeeder@agTEK.2020_2_mqtt' \
    -t 'WCN-A100-0001X/diet/dlink/data' \
    -m '{"rfid":19946219,"diet_id":12345}'
```

---

## 6. Docker Deployment (Optional)

### 6.1 Dockerfile

```dockerfile
FROM ubuntu:22.04

RUN apt update && apt install -y \
    cmake build-essential g++ \
    libmosquitto-dev libsqlite3-dev libwiringpi-dev \
    && rm -rf /var/lib/apt/lists/*

WORKDIR /opt/wifeeder-v2
COPY raspberry/ .

RUN mkdir build && cd build && \
    cmake .. -DCMAKE_BUILD_TYPE=Release && \
    cmake --build . -j$(nproc)

ENTRYPOINT ["./build/wifeeder_host"]
```

### 6.2 Use Docker Compose

```yaml
# docker-compose.yml
version: '3'
services:
  wifeeder:
    build: .
    privileged: true
    devices:
      - /dev/spidev0.0:/dev/spidev0.0
      - /dev/spidev0.1:/dev/spidev0.1
      - /dev/gpiomem:/dev/gpiomem
    volumes:
      - /etc/wifeeder-v2:/etc/wifeeder-v2
      - /var/log:/var/log
    restart: always
```

```bash
docker-compose up -d
docker-compose logs -f
```

---

## 7. Deployment Checklist

### Pre-Deployment

- [ ] NRF24L01+ wired correctly on both sides
- [ ] NRF test passes (both STM32 and RPi)
- [ ] RFID reader responds to tags
- [ ] Motors spin correctly (both directions)
- [ ] Encoders count accurately
- [ ] HX711 calibrated (if used)
- [ ] Database initialized with schema
- [ ] MQTT broker running and accessible
- [ ] Config files set with correct values

### Deployment

- [ ] Flash STM32 firmware
- [ ] Configure STM32 via CLI (device ID, type, channel)
- [ ] Install RPi software
- [ ] Start systemd service
- [ ] Verify STATUS messages in logs
- [ ] Test full feed cycle
- [ ] Verify MQTT events in cloud
- [ ] Check database updates
- [ ] Monitor for 1 hour

### Post-Deployment

- [ ] Check log for errors
- [ ] Verify battery voltage
- [ ] Test disconnection recovery
- [ ] Test power cycle recovery
- [ ] Document any issues

---

## 8. Health Monitoring

```bash
#!/bin/bash
# scripts/health_check.sh

echo "=== WiFeeder v2 Health Check ==="
echo

# Check service
if systemctl is-active --quiet wifeeder-v2; then
    echo "✅ Service: running"
else
    echo "❌ Service: stopped"
fi

# Check database
if [ -f /etc/wifeeder-v2/wifeeder.db ]; then
    echo "✅ Database: exists"
else
    echo "❌ Database: missing"
fi

# Check SPI
if [ -e /dev/spidev0.0 ]; then
    echo "✅ SPI: enabled"
else
    echo "❌ SPI: disabled"
fi

# Check MQTT
if mosquitto_sub -h localhost -t '$SYS/#' -C 1 -W 2 > /dev/null 2>&1; then
    echo "✅ MQTT: connected"
else
    echo "❌ MQTT: not responding"
fi

# Recent feeds
echo
echo "--- Recent Feeds ---"
sqlite3 /etc/wifeeder-v2/wifeeder.db \
    "SELECT datetime(timestamp, 'unixepoch'), rfid, motor1_actual
     FROM feed_history ORDER BY timestamp DESC LIMIT 5;"
```

---

## 9. Rollback Procedure

If v2 deployment fails:

```bash
# Stop v2 service
sudo systemctl stop wifeeder-v2
sudo systemctl disable wifeeder-v2

# Restore v1 (if still installed)
sudo systemctl enable controller
sudo systemctl start controller

# Or reboot to previous state
sudo reboot
```

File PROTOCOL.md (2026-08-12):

# WiFeeder v2 — NRF24L01+ Communication Protocol

> **Version**: 2.0.0  
> **Transport**: NRF24L01+ Enhanced ShockBurst  
> **Data Rate**: 1 Mbps  
> **Payload**: 32 bytes max per packet  

---

## Table of Contents

1. [NRF24L01+ Configuration](#nrf24l01-configuration)
2. [Packet Format](#packet-format)
3. [Message Types](#message-types)
4. [Communication Flows](#communication-flows)
5. [Error Handling & Retry](#error-handling--retry)
6. [Security & Addressing](#security--addressing)

---

## 1. NRF24L01+ Configuration

### 1.1 Radio Parameters

| Parameter | Value | Reason |
|---|---|---|
| **Channel** | 76 (2.476 GHz) | Production default (`PROTOCOL` / firmware / tests 09–10). Lab-only SI24R1 note: try 64 via `sweep` |
| **Data Rate** | 1 Mbps | Best balance range/speed |
| **TX Power** | 0 dBm | Default; upgrade to +7 dBm if needed |
| **CRC** | 16-bit (NRF hardware) | Built-in packet integrity |
| **Auto-Ack** | Enabled (pipe 0) | Free reliability layer |
| **Retries** | 10 retries, 500 μs delay | Protocol layer also handles retries |
| **Address Width** | 5 bytes | Standard NRF24L01+ |
| **Payload Size** | 32 bytes (dynamic) | ADR enabled |

### 1.2 Pipe Configuration

```mermaid
graph TB
    subgraph STM32["STM32 (Actuator) - TX Mode"]
        S_P0["Pipe 0: RX_ADDR = 0xE7E7E7E7E7<br/>(for auto-ACK)"]
        S_TX["TX_ADDR    = 0xE7E7E7E7E7<br/>(RPi address)"]
    end

    subgraph RPI["Raspberry Pi (Controller) - RX Mode"]
        R_P0["Pipe 0: RX_ADDR = 0xE7E7E7E7E7<br/>(listen to STM32)"]
        R_TX["TX_ADDR    = 0xE7E7E7E7E7<br/>(for ACK responses)"]
    end

    S_TX <-.-> |"2.4 GHz<br/>Packet + ACK"| R_P0
```

### 1.3 Initialization Sequence

```mermaid
sequenceDiagram
    participant MCU as Microcontroller
    participant NRF as NRF24L01+

    MCU->>NRF: FLUSH_TX / FLUSH_RX
    MCU->>NRF: CONFIG = 0x0E (RX/TX modes off)
    MCU->>NRF: SETUP_RETR = 0x1A (500μs, 10 retries)
    MCU->>NRF: RF_CH = 76 (2.476 GHz)
    MCU->>NRF: RF_SETUP = 0x06 (1 Mbps, 0 dBm)
    MCU->>NRF: EN_AA = 0x01 (auto-ACK on pipe 0)
    MCU->>NRF: EN_RXADDR = 0x01 (enable pipe 0)
    MCU->>NRF: SETUP_AW = 0x03 (5-byte address)
    MCU->>NRF: RX_PW_P0 = 32 (32-byte payload)
    Note over MCU,NRF: Configure addresses...
    MCU->>NRF: Write TX_ADDR
    MCU->>NRF: Write RX_ADDR_P0
    MCU->>NRF: CE = HIGH (start listening/transmitting)
    NRF-->>MCU: Ready for communication
```

---

## 2. Packet Format

### 2.1 Application-Level Packet

```
Byte Offset  0        1        2        3       4-31
            ┌────────┬────────┬────────┬────────┬──────────────┐
            │ Dest   │ Src    │ Msg    │ Seq    │ Payload +    │
            │ ID     │ ID     │ Type   │ Num    │ CRC-8        │
            │ 1 B    │ 1 B    │ 1 B    │ 1 B    │ 0-28 B       │
            └────────┴────────┴────────┴────────┴──────────────┘
                                              Last byte = CRC-8
```

| Field | Size | Description |
|---|---|---|
| **Dest ID** | 1 byte | Destination device ID (0x00 = Controller, 0x01-0xFE = Actuator) |
| **Src ID** | 1 byte | Source device ID |
| **Msg Type** | 1 byte | Message type (see below) |
| **Seq Num** | 1 byte | Rolling sequence number for duplicate detection |
| **Payload** | 0-27 bytes | Message-specific data |
| **CRC-8** | 1 byte | CRC-8 over bytes 0..(n-1), polynomial 0x07 |

Total: **4-32 bytes** fits in one NRF24L01+ packet.

### 2.2 Packet Lifecycle

```mermaid
sequenceDiagram
    participant App as Application
    participant Proto as Protocol Layer
    participant NRF as NRF24L01+ HW

    App->>Proto: Send(message)
    Proto->>Proto: Pack (dest, src, type, seq, payload)
    Proto->>Proto: Calculate CRC-8
    Proto->>NRF: Write 32-byte packet to TX FIFO
    NRF->>NRF: Transmit + wait for auto-ACK

    alt ACK received
        NRF-->>Proto: TX_SUCCESS
        Proto-->>App: Success
    else No ACK (max retries)
        NRF-->>Proto: MAX_RT (max retry reached)
        Proto->>NRF: FLUSH_TX
        Proto->>Proto: Retry at application level
        Proto->>NRF: Re-send packet
    end
```

---

## 3. Message Types

### 3.1 Message Type Overview

```mermaid
graph TB
    subgraph Messages["Message Types"]
        M1["0x01 - STATUS<br/>(STM32→RPi)<br/>Heartbeat + sensors"]
        M2["0x02 - RFID_TAG<br/>(STM32→RPi)<br/>Tag detected"]
        M3["0x03 - FEED_CMD<br/>(RPi→STM32)<br/>Start feeding"]
        M4["0x04 - FEED_DONE<br/>(STM32→RPi)<br/>Feeding complete"]
        M5["0x05 - WEIGHT<br/>(STM32→RPi)<br/>Weight data"]
        M6["0x06 - CONFIG<br/>(RPi→STM32)<br/>Config update"]
        M7["0x07 - ACK<br/>(Both directions)<br/>Acknowledge"]
        M8["0x08 - ERROR<br/>(Both directions)<br/>Error report"]
    end
```

### 3.2 STATUS (0x01) — STM32 → RPi

**Sent**: Every 5 seconds (heartbeat), or 1 second if disconnected.

```
Byte Offset  4         5               6               7        8
            ┌─────────┬───────────────┬───────────────┬────────┬────────┐
            │ Heartbeat│ Sensor Status │ Battery Level │ Resvd │ CRC-8  │
            │ uint32   │ uint8         │ uint8         │ [3B]  │ 1 B    │
            └─────────┴───────────────┴───────────────┴────────┴────────┘

Sensor Status (byte 5):
  Bit 0: Motor 1 OK      (0=OK, 1=fault)
  Bit 1: Motor 2 OK      (0=OK, 1=fault)
  Bit 2: RFID OK         (0=OK, 1=fault)
  Bit 3: HX711 OK        (0=OK, 1=fault)
  Bit 4: Connection LED  (0=off, 1=on)
  Bit 5-7: Reserved

Battery Level (byte 6):
  0-100: Percentage (0xFF = unknown)
```

### 3.3 RFID_TAG (0x02) — STM32 → RPi

**Sent**: When RFID reader detects a valid tag.

```
Byte Offset  4          5-7             8
            ┌──────────┬───────────────┬────────┐
            │ Tag ID   │ Timestamp     │ CRC-8  │
            │ uint32   │ uint24 (ms)   │ 1 B    │
            └──────────┴───────────────┴────────┘

Tag ID: 26-bit EM4100 format (decimal)
Timestamp: Uptime in milliseconds when tag was read
```

### 3.4 FEED_CMD (0x03) — RPi → STM32

**Sent**: In response to RFID_TAG, after diet calculation.

```
Byte Offset  4-7         8-9               10-11             12
            ┌───────────┬─────────────────┬─────────────────┬────────┐
            │ Animal ID │ Motor 1 Revs    │ Motor 2 Revs    │ CRC-8  │
            │ uint32    │ uint16          │ uint16          │ 1 B    │
            └───────────┴─────────────────┴─────────────────┴────────┘

Animal ID:  26-bit RFID tag ID
Motor 1 Revs: Target revolutions for main motor
Motor 2 Revs: Target revolutions for complementary motor
```

### 3.5 FEED_DONE (0x04) — STM32 → RPi

**Sent**: After motors have completed their revolutions.

```
Byte Offset  4-7         8-9               10-11             12
            ┌───────────┬─────────────────┬─────────────────┬────────┐
            │ Animal ID │ Motor 1 Actual  │ Motor 2 Actual  │ CRC-8  │
            │ uint32    │ uint16          │ uint16          │ 1 B    │
            └───────────┴─────────────────┴─────────────────┴────────┘

Animal ID:    26-bit RFID tag ID
Motor 1 Actual: Actual revolutions dispensed (encoder count / 400)
Motor 2 Actual: Actual revolutions dispensed
```

### 3.6 WEIGHT (0x05) — STM32 → RPi

**Sent**: After weighing sequence completes.

```
Byte Offset  4-7         8-11            12
            ┌───────────┬───────────────┬────────┐
            │ Animal ID │ Weight (g)     │ CRC-8  │
            │ uint32    │ uint32        │ 1 B    │
            └───────────┴───────────────┴────────┘

Animal ID: 26-bit RFID tag ID (0 if standalone weighing)
Weight:    Weight in grams
```

### 3.7 CONFIG (0x06) — RPi → STM32

**Sent**: To update actuator configuration.

```
Byte Offset  4          5-8            9
            ┌──────────┬──────────────┬────────┐
            │ Param ID │ Value        │ CRC-8  │
            │ uint8    │ uint32       │ 1 B    │
            └──────────┴──────────────┴────────┘

Param IDs:
  0x01: Device Station ID
  0x02: Heartbeat interval (seconds)
  0x03: Motor speed (PWM 0-100%)
  0x04: RFID timeout (seconds)
```

### 3.8 ACK (0x07) — Both Directions

**Sent**: In response to any message to confirm receipt.

```
Byte Offset  4              5            6
            ┌──────────────┬────────────┬────────┐
            │ Echo Msg Type│ Status     │ CRC-8  │
            │ uint8        │ uint8      │ 1 B    │
            └──────────────┴────────────┴────────┘

Echo Msg Type: The MsgType being acknowledged
Status:
  0x00: OK
  0x01: Bad CRC
  0x02: Unknown message type
  0x03: Buffer full
```

### 3.9 ERROR (0x08) — Both Directions

**Sent**: When an unrecoverable error occurs.

```
Byte Offset  4              5-8            9
            ┌──────────────┬──────────────┬────────┐
            │ Error Code   │ Details       │ CRC-8  │
            │ uint8        │ uint32       │ 1 B    │
            └──────────────┴──────────────┴────────┘

Error Codes:
  0x01: Motor stall detected
  0x02: RFID read failure
  0x03: HX711 timeout
  0x04: Watchdog reset imminent
  0x05: Battery low
  0x06: Memory allocation failure
  0xFF: Unknown error (details in payload)
```

---

## 4. Communication Flows

### 4.1 Normal Feeding Sequence

```mermaid
sequenceDiagram
    participant Cow as  Cow
    participant RFID as RFID Reader
    participant STM32 as STM32 MCU
    participant NRF as NRF24L01+
    participant RPi as Raspberry Pi
    participant DB as Database

    rect rgb(240, 248, 255)
        Note over STM32,RPi: Regular heartbeat (every 5s)
        STM32->>NRF: STATUS (0x01)
        NRF->>RPi: RF packet
        RPi->>NRF: ACK (0x07)
    end

    Cow->>RFID: Approaches feeder
    RFID->>STM32: Tag detected
    STM32->>NRF: RFID_TAG (0x02)
    NRF->>RPi: RF packet
    RPi->>DB: Lookup animal (RFID)
    DB->>RPi: Diet data
    RPi->>RPi: Calculate portion
    RPi->>NRF: FEED_CMD (0x03)
    NRF->>STM32: RF packet
    STM32->>STM32: Start motors
    Note over STM32: Feeding in progress...
    STM32->>NRF: FEED_DONE (0x04)
    NRF->>RPi: RF packet
    RPi->>DB: Update consumption
```

### 4.2 Weighing Sequence

```mermaid
sequenceDiagram
    participant RFID as RFID Reader
    participant STM32 as STM32 MCU
    participant NRF as NRF24L01+
    participant RPi as Raspberry Pi

    rect rgb(255, 248, 240)
        Note over STM32,RPi: Animal on scale
        RFID->>STM32: Tag detected
        STM32->>NRF: RFID_TAG (0x02)
        NRF->>RPi: RF packet
    end

    STM32->>STM32: Read HX711 (20 samples)
    STM32->>NRF: WEIGHT (0x05)
    NRF->>RPi: RF packet (weight in grams)
    RPi->>RPi: Store weight in DB
    RPi->>RPi: Publish to MQTT
```

### 4.3 Disconnection Recovery

```mermaid
sequenceDiagram
    participant STM32 as STM32 MCU
    participant NRF as NRF24L01+
    participant RPi as Raspberry Pi

    Note over STM32,RPi: Normal operation
    STM32->>NRF: STATUS (0x01)
    NRF->>RPi:  ACK received

    Note over STM32,RPi: RPi goes offline
    STM32->>NRF: STATUS (0x01)
    NRF-->>STM32:  MAX_RT (no ACK)

    rect rgb(255, 235, 238)
        STM32->>STM32: Switch to 1s heartbeat
        loop Every 1 second
            STM32->>NRF: STATUS (0x01)
            NRF-->>STM32:  No ACK
            Note over STM32: LED blinks fast
        end
    end

    Note over STM32,RPi: RPi comes back online
    STM32->>NRF: STATUS (0x01)
    NRF->>RPi:  ACK received
    RPi->>NRF: ACK (0x07)
    NRF->>STM32: ACK received

    rect rgb(232, 245, 233)
        STM32->>STM32: Switch to 5s heartbeat
        Note over STM32: LED on solid
    end
```

---

## 5. Error Handling & Retry

```mermaid
stateDiagram-v2
    [*] --> TX_READY: Message queued

    TX_READY --> SENDING: Write to NRF TX FIFO
    SENDING --> TX_OK: Auto-ACK received
    SENDING --> TX_FAIL: MAX_RT (max retries reached)

    TX_OK --> [*]: Done

    TX_FAIL --> FLUSH: FLUSH_TX
    FLUSH --> RETRY_CHECK: Check retry count

    RETRY_CHECK --> TX_READY: Retries < 3
    RETRY_CHECK --> CONN_LOST: Retries >= 3

    CONN_LOST --> RECONNECT: Mark connection lost
    RECONNECT --> TX_READY: Wait 1s, try again
```

### Retry Parameters

| Parameter | Value |
|---|---|
| NRF hardware retries | 10 (auto-ACK timeout × 10) |
| Retry delay (NRF) | 500 μs between retries |
| Application retries | 3 |
| Application retry delay | 100 ms between retries |
| Disconnect threshold | 3 consecutive failures |
| Reconnect interval | 1 second (during disconnection) |

---

## 6. Security & Addressing

### 6.1 Device Addressing Scheme

```mermaid
graph TB
    subgraph Farm["Farm Network"]
        Controller["RPi Controller<br/>ID = 0x00"]
        A1["Actuator 1<br/>ID = 0x01"]
        A2["Actuator 2<br/>ID = 0x02"]
        A3["Actuator 3<br/>ID = 0x03"]
        A4["...<br/>ID = 0x04-0xFE"]
    end

    Controller <--> |"Pipe 0<br/>0xE7E7E7E7E7"| A1
    Controller <--> |"Pipe 1<br/>0xC2C2C2C2C2"| A2
    Controller <--> |"Pipe 2<br/>0xC2C2C2C2C3"| A3
    Controller <--> |"Pipe 3-5"| A4

    note right of Controller
        NRF24L01+ supports 6 RX pipes.
        For >6 actuators, use time-sliced
        addressing or multiple NRF modules.
    end note
```

### 6.2 Multi-Actuator Protocol

```mermaid
sequenceDiagram
    participant RPi as RPi (ID=0x00)
    participant A1 as Actuator 1 (ID=0x01)
    participant A2 as Actuator 2 (ID=0x02)

    Note over RPi,A2: RPi polls each actuator for status
    loop Every 5 seconds
        RPi->>A1: STATUS_REQ to 0x01
        A1->>RPi: STATUS (0x01)
        RPi->>A2: STATUS_REQ to 0x02
        A2->>RPi: STATUS (0x01)
    end

    Note over A1: Cow detected at Actuator 1
    A1->>RPi: RFID_TAG (0x02) - animal ID 19946219
    RPi->>RPi: Lookup animal in DB
    RPi->>A1: FEED_CMD (0x03) - 3 revs motor 1
    A1->>A1: Dispense feed
    A1->>RPi: FEED_DONE (0x04)
    RPi->>RPi: Update DB, publish MQTT
```

---

## 7. CRC-8 Implementation

### 7.1 Parameters

| Parameter | Value |
|---|---|
| Polynomial | 0x07 (x^8 + x^2 + x + 1) |
| Initial value | 0x00 |
| Final XOR | 0x00 |
| Reflected | No |

### 7.2 C Implementation

```c
uint8_t crc8(uint8_t *data, size_t len) {
    uint8_t crc = 0;
    for (size_t i = 0; i < len; i++) {
        crc ^= data[i];
        for (int j = 0; j < 8; j++) {
            if (crc & 0x80) crc = (crc << 1) ^ 0x07;
            else            crc = (crc << 1);
        }
    }
    return crc;
}
```

---

## 8. Performance

| Metric | Value |
|---|---|
| Packet air time (32 bytes, 1 Mbps) | ~320 μs |
| Turnaround (TX → ACK → ready) | ~250 μs |
| Effective throughput | ~500 kbps |
| Max actuators per RPi | 6 (1 per NRF pipe) |
| Max actuators (time-sliced) | 30+ |
| Range (indoor, 0 dBm) | ~30m |
| Range (outdoor, 0 dBm) | ~100m |
| Range (outdoor, +7 dBm) | ~500m |

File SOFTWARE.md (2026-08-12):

# WiFeeder v2 — Software Architecture

> **MCU (today)**: Bare-metal superloop (`wifeeder_init` / `wifeeder_poll`) — FreeRTOS vendored but **not linked** yet  
> **Motor PWM**: PCA9685 over bit-bang I2C (PB6/PB7)  
> **Host**: C++17 + CMake · diet/DB/MQTT/NRF  

---

## 1. STM32 Firmware Architecture

### 1.0 Current runtime (MVP)

```mermaid
flowchart LR
  main["main.c"] --> init["wifeeder_init"]
  main --> loop["wifeeder_poll"]
  init --> pca["pca9685 + motor"]
  init --> enc["encoder TIM2"]
  init --> nrf["nrf24l01"]
  loop --> status["STATUS"]
  loop --> feed["FEED_CMD / FEEDING"]
```

FreeRTOS task split below is the **target** model, not what `CMakeLists.txt` builds today.

### 1.1 Task Hierarchy (planned)

```mermaid
graph TB
    subgraph Kernel["FreeRTOS Kernel"]
        direction TB
        S["Scheduler<br/>(Preemptive)"]
    end

    subgraph Tasks["Application Tasks"]
        T1["CmdTask<br/>Prio: BelowNormal<br/>Stack: 512 words<br/>UART CLI + Debug"]
        T2["WifeederTask<br/>Prio: Normal<br/>Stack: 1024 words<br/>Main Control Loop"]
        T3["RadioTask<br/>Prio: AboveNormal<br/>Stack: 512 words<br/>NRF24L01+ TX/RX"]
        T4["IwdgTask<br/>Prio: Low<br/>Stack: 256 words<br/>Watchdog Refresh"]
    end

    S --> T1
    S --> T2
    S --> T3
    S --> T4

    T2 --> |"Queues"| T3
    T3 --> |"Queues"| T2
    T1 --> |"Commands"| T2
```

### 1.2 Module Dependency Graph

```mermaid
graph TB
    subgraph App["Application Layer"]
        MAIN["main.c<br/>Init + Task Creation"]
        WIFEEDER["wifeeder.c<br/>Main Loop + State Machine"]
        CMD["cmd.c<br/>CLI Command Handler"]
    end

    subgraph Drivers["Driver Layer"]
        NRF["nrf24l01.c<br/>SPI + NRF Protocol"]
        RFID["rfid.c<br/>UART2 + Tag Parsing"]
        MOTOR["motor.c<br/>PWM + IBT-2 Control"]
        ENCODER["encoder.c<br/>TIM2/3 Quadrature"]
        HX711_DRV["hx711.c<br/>Load Cell Reading"]
        FLASH["flash.c<br/>Config Storage"]
    end

    subgraph HAL["HAL Layer"]
        SPI["STM32 HAL SPI"]
        UART["STM32 HAL UART"]
        TIM["STM32 HAL TIM"]
        GPIO["STM32 HAL GPIO"]
    end

    subgraph Common["Common Libraries"]
        CRC["crc8.c<br/>CRC-8 Checksum"]
        ERROR["error.h<br/>Error Codes"]
        UTIL["utilities.c<br/>String Conversion"]
    end

    WIFEEDER --> NRF
    WIFEEDER --> RFID
    WIFEEDER --> MOTOR
    WIFEEDER --> ENCODER
    WIFEEDER --> HX711_DRV
    WIFEEDER --> FLASH

    NRF --> SPI
    NRF --> GPIO
    RFID --> UART
    MOTOR --> TIM
    MOTOR --> GPIO
    ENCODER --> TIM
    HX711_DRV --> GPIO

    WIFEEDER --> CRC
    WIFEEDER --> ERROR
    WIFEEDER --> UTIL
    NRF --> CRC
```

### 1.3 NRF24L01+ Driver API

```mermaid
classDiagram
    class NRF24L01 {
        +nrf24_init() T_eError_eErrorType
        +nrf24_send(uint8_t* data, size_t len) T_eError_eErrorType
        +nrf24_receive(uint8_t* data, size_t* len) T_eError_eErrorType
        +nrf24_is_data_available() bool
        +nrf24_set_channel(uint8_t ch) void
        +nrf24_set_power(uint8_t power) void
        -spi_transfer(uint8_t cmd) uint8_t
        -spi_write_register(uint8_t reg, uint8_t val) void
        -spi_read_register(uint8_t reg) uint8_t
        -flush_tx() void
        -flush_rx() void
    }

    class Protocol {
        +protocol_send_status(uint32_t heartbeat) T_eError_eErrorType
        +protocol_send_rfid(uint32_t tag_id) T_eError_eErrorType
        +protocol_send_feed_done(uint32_t animal_id, uint16_t m1, uint16_t m2) T_eError_eErrorType
        +protocol_send_weight(uint32_t animal_id, uint32_t grams) T_eError_eErrorType
        +protocol_receive(msg_t* msg) T_eError_eErrorType
        -pack(msg_t* msg, uint8_t* buf) void
        -unpack(uint8_t* buf, msg_t* msg) T_eError_eErrorType
        -crc8(uint8_t* data, size_t len) uint8_t
    }

    Protocol --> NRF24L01 : uses
```

### 1.4 Timer Allocations

> **L432KC note:** This MCU has **no TIM3 / TIM4 / TIM8**. Use TIM1 + TIM16 for PWM and TIM2 for Enc1. Enc2 is soft EXTI (PA11/PA12). See [`docs/wifeeder-v2-final-plan.md`](docs/wifeeder-v2-final-plan.md) §2.

| Timer | Channel | Function | Frequency |
|---|---|---|---|
| TIM1 | CH1 | PWM Motor 1 (PA8) | 10 kHz |
| TIM16 | CH1 | PWM Motor 2 (PB6) | 10 kHz |
| TIM2 | CH1, CH2 | Encoder 1 (PA0/PA1) | 400 PPR × 4 = 1600 cnt/rev |
| SysTick | - | FreeRTOS tick / HAL tick | 1 kHz |

### 1.5 Memory Map

```
FLASH (256 KB):
  0x0800_0000 - 0x0800_7FFF : Bootloader (32 KB)
  0x0800_8000 - 0x0800_FFFF : Application (32 KB)
  0x0801_0000 - 0x0801_7FFF : Config Pages (32 KB)
  0x0801_8000 - 0x0803_FFFF : Reserved (160 KB)

RAM (64 KB):
  0x2000_0000 - 0x2000_0FFF : Stack (4 KB)
  0x2000_1000 - 0x2000_7FFF : Heap + FreeRTOS (28 KB)
  0x2000_8000 - 0x2000_FFFF : Static Data + BSS (32 KB)
```

---

## 2. Raspberry Pi Software Architecture

### 2.1 Thread Model

```mermaid
graph TB
    subgraph Main["Main Process (wcontroller)"]
        direction TB

        subgraph Threads["Threads"]
            T1["NRF Thread<br/>Radio RX/TX<br/>Prio: High"]
            T2["Diet Thread<br/>Feed Calculation<br/>Prio: Normal"]
            T3["MQTT Thread<br/>Cloud Sync<br/>Prio: Normal"]
            T4["Web Thread<br/>Dashboard<br/>Prio: Low"]
        end

        subgraph Shared["Shared Resources"]
            DB["SQLite DB<br/>(Mutex Protected)"]
            NRF_QUEUE["NRF TX Queue<br/>(Thread-Safe)"]
            EVENT_QUEUE["Event Queue<br/>(Thread-Safe)"]
        end
    end

    T1 -->|"RX events"| EVENT_QUEUE
    EVENT_QUEUE -->|"Process"| T2
    T2 -->|"FEED_CMD"| NRF_QUEUE
    NRF_QUEUE -->|"TX"| T1
    T2 --> DB
    T3 --> DB
    T3 -->|"Config"| NRF_QUEUE
    T4 --> DB

    style T1 fill:#fff3e0
    style T2 fill:#e8f5e9
    style T3 fill:#e8eaf6
    style T4 fill:#f3e5f5
```

### 2.2 Class Diagram

```mermaid
classDiagram
    class Nrf24l01 {
        -int spi_fd
        -int ce_pin
        -int irq_pin
        +init() bool
        +send(uint8_t* data, size_t len) bool
        +receive(uint8_t* data, size_t* len) bool
        +dataAvailable() bool
        -spiTransfer(uint8_t* tx, uint8_t* rx, size_t len) void
    }

    class Protocol {
        +sendStatus(uint32_t heartbeat) bool
        +sendRfid(uint32_t tagId) bool
        +sendFeedCmd(FeedCmd cmd) bool
        +receive(Message* msg) bool
        -pack(Message* msg, uint8_t* buf) void
        -unpack(uint8_t* buf, Message* msg) bool
        -crc8(uint8_t* data, size_t len) uint8_t
    }

    class DietEngine {
        +calcPortion(uint32_t rfid) FeedCmd
        +updateConsumption(uint32_t rfid, uint16_t actual)
        +getDailyStatus(uint32_t rfid) DietStatus
        -getTargetDailyQty(uint32_t rfid) double
        -getCurrentConsumption(uint32_t rfid) double
        -getRemainingPortions(uint32_t rfid) uint32_t
    }

    class Database {
        -sqlite3* db
        -std::mutex mtx
        +open() bool
        +getAnimal(uint32_t rfid) Animal
        +updateConsumption(uint32_t rfid, uint16_t qty) bool
        +getWeight(uint32_t rfid) double
        +storeWeight(uint32_t rfid, double weight) bool
        +getAllActiveRfids() vector~uint32_t~
    }

    class MqttClient {
        -mosquitto* mqtt
        +connect() bool
        +publishFeed(uint32_t rfid, uint16_t actual) bool
        +publishWeight(uint32_t rfid, double grams) bool
        +subscribe(string topic) bool
        -onMessage(string topic, string payload) void
    }

    Protocol --> Nrf24l01 : uses
    DietEngine --> Database : queries
    DietEngine --> Protocol : sends FEED_CMD
    MqttClient --> Database : reads/writes
```

### 2.3 Event Processing Pipeline

```mermaid
sequenceDiagram
    participant NRF_Thread as NRF Thread
    participant EventQ as Event Queue
    participant Diet_Thread as Diet Thread
    participant DB as Database
    participant MQTT_Thread as MQTT Thread
    participant Cloud as Agpro Cloud

    NRF_Thread->>NRF_Thread: Packet received
    NRF_Thread->>NRF_Thread: Parse + validate CRC
    NRF_Thread->>EventQ: Push(event)
    EventQ->>Diet_Thread: Pop(event)

    alt RFID_TAG event
        Diet_Thread->>DB: Lookup animal (RFID)
        DB->>Diet_Thread: Diet data
        Diet_Thread->>Diet_Thread: Calc portion
        Diet_Thread->>NRF_Thread: Send FEED_CMD
    else FEED_DONE event
        Diet_Thread->>DB: Update consumption
        DB->>Diet_Thread: OK
        Diet_Thread->>MQTT_Thread: Publish feed event
        MQTT_Thread->>Cloud: MQTT message
    else WEIGHT event
        Diet_Thread->>DB: Store weight
        Diet_Thread->>MQTT_Thread: Publish weight
        MQTT_Thread->>Cloud: MQTT message
    end
```

### 2.4 Database Schema

```mermaid
erDiagram
    ANIMALS {
        uint32 rfid PK
        string name
        uint32 diet_id FK
        double weight_kg
        uint64 weight_ts
    }

    DIETS {
        uint32 diet_id PK
        uint8 feed_id
        string start_time
        string end_time
        uint32 inter_seconds
        uint32 d_max_grams
        uint32 d_qty_grams
        uint32 p_max_grams
        uint32 density
    }

    CONSUMPTION {
        uint32 id PK
        uint32 rfid FK
        uint32 diet_id FK
        uint32 feed_id FK
        double day_weight
        double day_left
        uint32 day_ports
        string date
    }

    FEED_HISTORY {
        uint32 id PK
        uint32 rfid FK
        uint16 motor1_actual
        uint16 motor2_actual
        uint64 timestamp
    }

    WEIGHTS {
        uint32 id PK
        uint32 rfid FK
        double weight_g
        uint64 timestamp
    }

    ACTUATORS {
        uint8 station_id PK
        uint8 motor1_status
        uint8 motor2_status
        uint8 rfid_status
        uint8 hx711_status
        uint64 last_seen
    }

    ANIMALS ||--o{ CONSUMPTION : has
    ANIMALS ||--o{ FEED_HISTORY : has
    ANIMALS ||--o{ WEIGHTS : has
    DIETS ||--o{ ANIMALS : assigned_to
    DIETS ||--o{ CONSUMPTION : tracked_by
    ACTUATORS ||--o{ FEED_HISTORY : produced_by
```

### 2.5 Config File Format (`config.json`)

```json
{
  "station": {
    "sn": "WCN-A100-0001X",
    "device_id": 0,
    "name": "Station 1"
  },
  "nrf24": {
    "spi_device": "/dev/spidev0.0",
    "ce_pin": 25,
    "irq_pin": 24,
    "channel": 76,
    "data_rate": "1Mbps",
    "tx_power_dbm": 0
  },
  "mqtt": {
    "broker": "localhost",
    "port": 1883,
    "username": "client2",
    "password": "wifeeder@agTEK.2020_2_mqtt",
    "keep_alive": 60,
    "qos": 2,
    "topic_prefix": "WCN-A100-0001X"
  },
  "database": {
    "path": "/etc/wifeeder-v2/wifeeder.db"
  },
  "feeding": {
    "algorithm": "linear_dynamic",
    "calibration_tag": 0,
    "intervals": {
      "status_ok": 5,
      "status_disconnected": 1
    }
  }
}
```

---

## 3. Build System

### 3.1 STM32 (CubeIDE / CMake)

```cmake
# stm32/CMakeLists.txt
cmake_minimum_required(VERSION 3.22)
project(wifeeder_v2_mcu C ASM)

set(CMAKE_C_STANDARD 99)
set(CMAKE_C_STANDARD_REQUIRED ON)

add_executable(wifeeder_mcu
    Core/Src/main.c
    Core/Src/nrf24l01.c
    Core/Src/protocol.c
    Core/Src/rfid.c
    Core/Src/motor.c
    Core/Src/encoder.c
    Core/Src/hx711.c
    Core/Src/flash.c
    Core/Src/cmd.c
    Core/Src/stm32l4xx_it.c
    startup/startup_stm32l432xx.s
)

target_link_libraries(wifeeder_mcu
    STM32_HAL
    FreeRTOS
    CMSIS
    Common
)
```

### 3.2 Raspberry Pi (CMake)

```cmake
# raspberry/CMakeLists.txt
cmake_minimum_required(VERSION 3.16)
project(wifeeder_v2_host CXX)

set(CMAKE_CXX_STANDARD 20)
set(CMAKE_CXX_STANDARD_REQUIRED ON)

add_executable(wifeeder_host
    src/main.cpp
    src/nrf24l01.cpp
    src/protocol.cpp
    src/diet_engine.cpp
    src/database.cpp
    src/mqtt_client.cpp
)

target_link_libraries(wifeeder_host
    PRIVATE PkgConfig::MOSQUITTO
    PRIVATE PkgConfig::SQLITE3
    PRIVATE pthread
    PRIVATE wiringPi
)
```

---

## 4. Key Data Structures

### 4.1 Message (Both Platforms)

```c
typedef struct __attribute__((packed)) {
    uint8_t  dest_id;
    uint8_t  src_id;
    uint8_t  msg_type;
    uint8_t  seq_num;
    union {
        struct { uint32_t heartbeat; uint8_t sensors; uint8_t battery; } status;
        struct { uint32_t tag_id;   uint32_t timestamp;               } rfid_tag;
        struct { uint32_t animal_id; uint16_t motor1_revs; uint16_t motor2_revs; } feed_cmd;
        struct { uint32_t animal_id; uint16_t motor1_actual; uint16_t motor2_actual; } feed_done;
        struct { uint32_t animal_id; uint32_t weight_g;               } weight;
        struct { uint8_t  param_id;  uint32_t value;                   } config;
        struct { uint8_t  echoed_type; uint8_t status;                 } ack;
        struct { uint8_t  error_code; uint32_t details;                } error;
    } payload;
    uint8_t crc;
} T_stWifeederV2_iMessage;
```

### 4.2 NRF Stats (Debugging)

```c
typedef struct {
    uint32_t packets_sent;
    uint32_t packets_received;
    uint32_t acks_received;
    uint32_t retries;
    uint32_t crc_errors;
    uint32_t max_rt_errors;
    uint32_t sequence_gaps;
    int8_t   last_rssi;
    uint32_t uptime_ms;
} T_stNrf_iStats;
```

---

## 5. Error Handling Strategy

```mermaid
stateDiagram-v2
    [*] --> NORMAL: System booted

    NORMAL --> WARNING: Connectivity issues
    NORMAL --> ERROR: Hardware fault

    WARNING --> NORMAL: Issue resolved
    WARNING --> ERROR: Issue persists > threshold

    ERROR --> RECOVERY: Attempt auto-recovery
    RECOVERY --> NORMAL: Recovery successful
    RECOVERY --> FATAL: Recovery failed 3x

    FATAL --> [*]: System reset / maintenance
```

### Error Response Matrix

| Error | STM32 Action | RPi Action |
|---|---|---|
| NRF TX fail (1x) | Retry app-level | Wait for next STATUS |
| NRF TX fail (3x) | Mark disconnected, 1s heartbeat | Log, alert MQTT |
| NRF TX fail (10x) | Increment fail counter | Alert MQTT, mark offline |
| RFID read fail | Retry 5x, then ignore | N/A |
| Motor stall | Stop motor, send ERROR | Log, alert MQTT |
| HX711 timeout | Send ERROR, retry next cycle | Log |
| Watchdog timeout | System reset | Log reset event |

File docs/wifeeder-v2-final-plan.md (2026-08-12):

# WiFeeder v2 — Final Project Plan for AI Agent

> **Status**: Wiring MVP + PCA9685 firmware path aligned (2026-08-03)  
> **Updated**: 2026-08-03  
> **Context**: Complete rewrite of v1 CAN-based cow feeding system using NRF24L01+ wireless  
> **v1 source**: `/home/luceor/Desktop/wifeeder/` (algorithms, Host threads, MCU feed loop, Docker/CMake)  
> **v1 spec**: `/home/luceor/Desktop/wifeeder/docs/WIFEEDER_Documentation.md`

**Product intent unchanged:** RFID → Host diet calc → dispense revs → feedback → MQTT.  
**Only the link changes:** SocketCAN / walink → **NRF24L01+**.

---

## 0. System Context

```mermaid
flowchart LR
  subgraph cloud [AgproCloud]
    MQTT[MQTT_Broker]
  end
  subgraph pi [RaspberryPi]
    Host[diet_sqlite_mqtt_nrf_link]
    Host --> MQTT
  end
  subgraph stm [NUCLEO_L432KC]
    Act[FreeRTOS_wifeeder]
  end
  Host <-->|"NRF24_32B"| Act
```

Diagrams: [`diagrams/PLAN-01-system-context.mmd`](../diagrams/PLAN-01-system-context.mmd) · [`PLAN-04-feed-sequence.mmd`](../diagrams/PLAN-04-feed-sequence.mmd)

---

## 1. What Exists Already

### 1.1 wifeeder-v2 (this repo)

| Artifact | Location | Status |
|---|---|---|
| Architecture docs + Mermaid | `*.md`, `diagrams/*.mmd` | Updated for PCA9685 MVP |
| Fritzing wiring pack | `wiring/` | Full + 6 block sketches |
| STM32 HAL/CMSIS (L4) | `stm32/Drivers/` | Present |
| STM32 app (superloop) | `stm32/Core/` | `wifeeder` + NRF + PCA9685 motor + Enc1 |
| FreeRTOS | `stm32/Middlewares/` | Vendored; **not linked** in CMake |
| Raspberry Pi host | `raspberry/` | C++17 NRF/diet/JSON/MQTT |
| Hardware tests 01–10 | `tests/` | Present; 04 = PCA motor |
| Docker image | `wifeeder-dev` | Working |

### 1.2 wifeeder v1 (port source — `/home/luceor/Desktop/wifeeder/`)

| Layer | Path | Status |
|---|---|---|
| Host (Pi) | `Host/src/main.cpp` + diet/DB/MQTT/walink | Production C++17 |
| MCU (actuator) | `MCU/app/Src/wifeeder.c` + FreeRTOS | Production on **STM32L486ZG** |
| FreeRTOS tree | `MCU/CubeMxProjects/.../FreeRTOS/` | Vendor into v2 |
| Shared CRC | `Common/` | Reuse |
| Docker/CMake | `docker/Dockerfile.dev`, `cmake/toolchain-*.cmake` | Reuse |
| Spec | `docs/WIFEEDER_Documentation.md` | Behaviors to preserve |

---

## 2. Critical Hardware — NUCLEO-L432KC Reality

### 2.1 Package limits (must not use dead pins)

STM32L432KC (UFQFPN32) / Nucleo-32 **does not have**: PB8–PB11, PC0–PC13, TIM3, TIM4.

Arduino Nano labels on this board (UM1956):

| Arduino | STM32 | Notes |
|---|---|---|
| D8 | **PC15** | OSC32 — avoid |
| D9 | **PA8** | TIM1_CH1 (was mislabeled D8=PA8 in older notes) |
| D6 | PB1 | NRF MISO |
| D13 | PB3 | Onboard LED LD3 |
| A4 / A6 | PA5 / PA7 | NRF SCK / MOSI |

**Board lessons (this unit):**

1. **PA6 is shorted to GND** — never use as MISO; use **PB1**.
2. Bit-bang SPI required (PB1 has no SPI AF).
3. NRF adapter VCC often needs **5V** into AM1117 (not bare 3.3V).
4. Production CSN = **PA4**. Motor PWM is on **PCA9685** (not TIM1 on PA8).
5. Never use L486-only PLL header macros on L432 — bit positions differ.
6. **One jumper per Nucleo pin** — see `wiring/CONNECTOR_MAP.md`.

### 2.2 Locked production pin map (MVP)

| Function | Pin | Notes |
|---|-----|---|
| NRF SCK / MOSI / MISO | PA5 / PA7 / **PB1** | Bit-bang SPI |
| NRF CSN / CE | **PA4** / PB0 | Adapter VCC=**5V** |
| LED | PB3 | Nucleo LD3 |
| PCA9685 SCL / SDA | **PB6** / **PB7** | I2C bit-bang (D5/D4) |
| Motor1 | PCA PWM0 / PWM1 → IBT RPWM/LPWM | EN→3.3V; OE→GND |
| Encoder 1 A/B | PA0 / PA1 | TIM2 ×4; GTS06 **600 P/R** |
| RFID / HX711 / Motor2 | deferred | Drivers exist; `WIFEEDER_MVP` |
| Debug UART | PA2 | LPUART1 → ST-Link VCP |

**MVP:** PCA9685 + 1 motor + Enc1 + NRF + LED.

Authority: [`wiring/CONNECTOR_MAP.md`](../wiring/CONNECTOR_MAP.md) · [`stm32/Core/Inc/board.h`](../stm32/Core/Inc/board.h)

### 2.3 Quick reference — NRF wiring (production)

```
NRF Adapter Pin → NUCLEO-L432KC
════════════════════════════════
VCC   → 5V    (AM1117 adapter; NOT bare 3.3V unless regulated)
GND   → GND
SCK   → PA5   (A4)
MOSI  → PA7   (A6)
MISO  → PB1   (D6)   [PA6 shorted — do not use]
CSN   → PA4   (A3)
CE    → PB0   (D3)
IRQ   → not connected (PB1 used for MISO)
Channel → 76 (production); lab SI24R1 note may use 64
```

### 2.4 Quick reference — PCA9685 + IBT-2 (production MVP)

```
Nucleo D5/PB6 → PCA SCL
Nucleo D4/PB7 → PCA SDA
Buck 3V3      → PCA VCC
Buck GND      → PCA GND + OE
PCA PWM0      → IBT RPWM (Motor 1)
PCA PWM1      → IBT LPWM (Motor 1)
Buck 3V3      → IBT R_EN / L_EN
NRF 5V daisy  → IBT VCC
Battery 12V   → IBT B+ / B−
IBT M+ / M−   → GX-2 → motor
```

---

## 3. Directory Structure to Create

### 3.1 STM32 production tree

```
stm32/
├── Core/
│   ├── Inc/
│   │   ├── nrf24l01.h      # Bit-bang SPI driver API
│   │   ├── protocol.h      # 32-byte pack/unpack + CRC8
│   │   ├── crc8.h
│   │   ├── rfid.h          # Port of v1 rfid_134khz parser
│   │   ├── motor.h         # IBT-2 PWM
│   │   ├── encoder.h
│   │   ├── hx711.h
│   │   ├── flash_int.h     # Device id/type (new flash map)
│   │   ├── wifeeder.h      # Port of v1 feed loop
│   │   └── wifeeder_cmd.h  # CLI
│   └── Src/
│       ├── main.c          # FreeRTOS init + tasks
│       ├── nrf24l01.c
│       ├── protocol.c
│       ├── crc8.c
│       ├── rfid.c
│       ├── motor.c
│       ├── encoder.c
│       ├── hx711.c
│       ├── flash_int.c
│       ├── wifeeder.c
│       ├── wifeeder_cmd.c
│       └── syscalls.c
├── Middlewares/            # Vendor FreeRTOS from v1 CubeMX tree
├── Drivers/                # Keep HAL/CMSIS
├── linker/  startup/  Config/
└── CMakeLists.txt
```

### 3.2 Raspberry Pi tree

```
raspberry/
├── src/
│   ├── main.cpp            # Port Host/src/main.cpp threads
│   ├── nrf24l01.cpp / nrf_link.cpp   # Replaces walink
│   ├── protocol.cpp
│   ├── diet.cpp            # Port from v1
│   ├── animal.cpp / weight.cpp / tool.cpp
│   ├── database.cpp        # API from v1; storage → SQLite
│   ├── mqtt_client.cpp
│   ├── scale.cpp / fwmgr.cpp / cli.cpp
│   └── feeder.cpp          # DO NOT port alternate eFeeder stack
├── include/
├── config/config.json
├── CMakeLists.txt
└── README.md
```

### 3.3 Test suite

```
tests/
├── README.md
├── CMakeLists.txt
├── 01-led/ … 08-nrf-pi/    # Self-contained mains (see §6)
└── common/test_utils.c
```

Replace empty `tests/{unit,integration,system}/` with the numbered hardware suite above (keep unit tests later under `tests/unit/` for diet GTest ports).

---

## 4. v1 → v2 Port Matrix

Diagram: [`diagrams/PLAN-06-v1-port-matrix.mmd`](../diagrams/PLAN-06-v1-port-matrix.mmd)

### 4.1 Host — port from `Host/`

| v1 file | v2 action | Notes |
|---|---|---|
| `Host/src/diet.cpp` | **Port as-is** | LINEAR_FORCED + extension |
| `animal.cpp`, `weight.cpp`, `tool.cpp` | **Port** | Data model |
| `database.cpp` | **Port API; → SQLite** | v1 JSON `/etc/wifeeder-data.json` |
| `mqtt_client.cpp` + topics | **Port** | `{SN}/diet\|weight/{ulink\|dlink}/{data\|async}` |
| `main.cpp` threads | **Port topology** | `walink_d` / `wserver_link_d` / `wcontroller_d` + scale/fwmgr/cli |
| `scale.cpp`, `fwmgr.cpp`, `cli.cpp` | **Port; rebind to nrf_link** | Same msg-type demux |
| `link/walink.cpp` | **Replace** | Keep API shape (`start/stop/sendto/recv`) |
| `can.cpp`, `can_intf.c` | **Drop** | No CAN |
| `feeder.cpp` (`eFeeder_*`) | **Do not port** | Production = diet+main |

**Preserve walink-like API:**

```cpp
class nrf_link {
public:
    T_eError_eErrorType init();
    void start();
    void stop();
    T_eError_eErrorType sendto(uint32_t msg_type, void* buf, size_t len, uint8_t dest);
    T_eError_eErrorType recv(uint32_t msg_type, void* buf, size_t* len);
};
```

### 4.2 MCU — port from `MCU/`

| v1 asset | Path | v2 action |
|---|---|---|
| Feeding loop | `MCU/app/Src/wifeeder.c` | Port into WifeederTask; CAN waits → NRF queues |
| Tasks | Cmd / Wifeeder / Iwdg | Reuse + add **RadioTask** |
| FreeRTOS | CubeMX Third_Party/FreeRTOS | Vendor into `stm32/Middlewares/` |
| RFID 134 kHz | `Drivers/RfId/Src/rfid_134khz.c` | Port parser; USART2/PA3 |
| HX711 math | `Drivers/Hx711/Src/hx711.c` | Port math; bit-bang PB4/PB5 |
| Encoder stall/overshoot | `Drivers/motor/gtk08.c` | Port algorithm; new pins |
| Flash id/type | `app/Src/flash_int.c` | Port pattern; **new 256 KB addresses** |
| CLI | `Middlewares/Cmd/` | Port to LPUART1 |
| CRC8 | `Common/` | Share via `crc8.c` |
| GTK08 On/Off motor | `gtk08.c` | **Rewrite** → IBT-2 PWM |
| CAN stack | — | **Drop** |
| L486 CubeMX/pins | `.ioc` | **Do not copy** |

### 4.3 Infra reuse

- Docker: `wifeeder/docker/Dockerfile.dev` → image `wifeeder-dev`
- Toolchain: `wifeeder/cmake/toolchain-arm-none-eabi.cmake`
- Finders: `FindFreeRTOS.cmake`, `FindCMSIS.cmake`, `FindSTM32HAL.cmake`
- Host GTest diet tests: port early (no HW)
- Smoke ELF checks: adapt `smoke_tests/`

---

## 5. Protocol Reconciliation

Diagram: [`diagrams/PLAN-07-protocol-map.mmd`](../diagrams/PLAN-07-protocol-map.mmd)

v1 has **two** encodings; v2 uses **one** NRF app protocol ([`PROTOCOL.md`](../PROTOCOL.md)).

| v1 CAN `T_eMsgType` | Role | v2 MsgType |
|---|---|---|
| Status (0) | Heartbeat + health | STATUS `0x01` |
| Ack (1) | Soft ACK | ACK `0x07` |
| FeedReq (2) | Tag needs diet | RFID_TAG `0x02` |
| FeedCmd (3) | Dispense revs | FEED_CMD `0x03` |
| FeedFdbk (4) | Actual revs | FEED_DONE `0x04` |
| FeedRsp (5) | Host confirms | ACK or omit (ESB) |
| WeightInd (6) | Grams | WEIGHT `0x05` |
| WeightRsp (7) | Confirm | ACK `0x07` |
| — | — | CONFIG `0x06`, ERROR `0x08` |

**Packet layout (32 B max):** `[DestID][SrcID][MsgType][Seq][Payload…][CRC-8]`  
CRC-8 poly 0x07 over bytes 0..n-1 (same spirit as v1 MCU CRC8).

**Addressing:** v1 Host CAN ID `0x01`, WA `0x02+` → DestID/SrcID + NRF pipe map. Multi-WA ≤30 still required.

**Do not port:** walink START/END 8-byte framing, `can_intf` bitfields, SocketCAN.

```mermaid
sequenceDiagram
  participant RFID as RFID_Reader
  participant STM as WifeederTask
  participant Radio as RadioTask_NRF
  participant Pi as nrf_link
  participant Diet as diet_engine
  participant Cloud as MQTT
  RFID->>STM: tag
  STM->>Radio: RFID_TAG
  Radio->>Pi: packet_32B
  Pi->>Diet: get_portion
  Diet->>Pi: mrevs_crevs
  Pi->>Radio: FEED_CMD
  Radio->>STM: revs
  STM->>STM: motor_encoder
  STM->>Radio: FEED_DONE
  Radio->>Pi: done
  Pi->>Cloud: ulink_consumption
```

---

## 6. Behavioral Contracts (acceptance criteria)

From v1 spec + `Host/src/diet.cpp` / `MCU/app/Src/wifeeder.c` — **must preserve**:

### Diet / feeding
- Windows: ordinary `[start,end)`, extension `end→midnight`, pause `midnight→start`
- Params: `inter`, `d_qty`, `d_max`, `p_max`, `density`, ≤2 feeds/diet
- Algo: `FEEDING_ALGO_LINEAR_FORCED`
- Grams↔revs: `DEF_CALIBER_REF_REVS=16`, `DEF_CALIBER_REF_WEIGHT=960`
- Caliber diet ID 1: always **exactly 16 revs**
- Daily reset ~**23:50**; missed carry; underfeed WARN/ALERT (50%/20%, 60%/40%)
- Unknown RFID → uplink async, no normal dispense
- Same-tag debounce **30 s**
- Caps: ~300 animals, 20 diets, ≤30 actuators

### Timeouts / reliability
- Status every **30 s**; fail retry **1 s**; **5 fails → MCU reset**
- Feed wait: **10 × 300 ms** (app-layer on NRF)
- Motor stall ~**1–1.5 s** no pulse → stop
- Host WA offline: **5 min** without RX → publish offline
- Local DB autonomy if MQTT down
- No feed unless link OK

### Motor / encoder
- GTS06 **600 P/R**; TIM2 ×4 → **2400** counts/rev (`BOARD_ENCODER_COUNTS_PER_REV`)
- Overshoot compensate ≤16 pulses (tune on bench)
- MVP single motor (v1 motor2 unused in run path)

---

## 7. FreeRTOS Task Model

Diagram: [`diagrams/PLAN-05-freertos-tasks.mmd`](../diagrams/PLAN-05-freertos-tasks.mmd)

| Task | Priority | Role | v1 origin |
|---|---|---|---|
| RadioTask | AboveNormal | NRF TX/RX + queues | New (replaces CAN poll) |
| WifeederTask | Normal | Port of `eWifeeder_eMainTask_Tsk` | `wifeeder.c` |
| CmdTask | BelowNormal | UART CLI | `Middlewares/Cmd` |
| IwdgTask | Low | Watchdog when round counter advances | `IwdgTask` |

Timers (L432 MVP): **TIM2** Encoder1, SysTick. Motor PWM = **PCA9685**. FreeRTOS later.

---

## 8. Test Program Specifications

### Test 01 — LED (`tests/01-led/`)
- Purpose: Board boots; GPIO works  
- Wiring: none (PB3)  
- Output: green LED ~2 s blink  
- Status: design ready (implement in Phase 2)

### Test 02 — UART (`tests/02-uart/`)
- Purpose: Serial on LPUART1 PA2 (VCP) or USART1 PA9 external cable  
- Clock: HSI 16 MHz for 115200  
- Output: `=== NUCLEO-L432KC UART OK ===` every 5 s

### Test 03 — NRF24L01+ (`tests/03-nrf/`)
- Purpose: Module responds to SPI  
- **Preserve** current `stm32/Core/Src/main.c` (CSN=PA8 bring-up OK)  
- Then add variant / note for production CSN=PA4  
- LED: ON 5s OFF 1s = PASS; ON 2s OFF 2s = FAIL

### Test 04 — Motor (`tests/04-motor/`)
- Purpose: PCA9685 → IBT-2 Motor1  
- Wiring: PB6/PB7 I2C → PWM0/PWM1 → RPWM/LPWM; EN→3.3V; OE→GND  
- LED: 3 blinks = PCA OK; fast blink = PCA fail  

### Test 05 — Encoder (`tests/05-encoder/`)
- Encoder A/B → PA0/PA1 (TIM2 encoder mode)

### Test 06 — RFID (`tests/06-rfid/`)
- RFID TX → PA3 (USART2_RX), 9600 8N1  
- Port frame parse from v1 `$A0112OKD` + XOR checksum

### Test 07 — HX711 (`tests/07-hx711/`)
- DOUT→**PB4**, SCK→**PB5** (not PC0/PC1)

### Test 08 — NRF on Pi (`tests/08-nrf-pi/`)
- SPI0: SCLK11 / MISO9 / MOSI10 / CE0=GPIO8; CE=GPIO25  
- TX/RX test packets with pigpio or spidev

---

## 9. Implementation Order

Diagram: [`diagrams/PLAN-02-phase-roadmap.mmd`](../diagrams/PLAN-02-phase-roadmap.mmd)

```mermaid
flowchart TB
  P1[Phase1_Structure] --> P2[Phase2_ComponentTests]
  P2 --> Gate{HW_tests_PASS}
  Gate -->|yes| P3[Phase3_STM_port]
  Gate -->|no| Fix[Fix_wiring]
  Fix --> P2
  P3 --> P4[Phase4_Pi_port]
  P4 --> P5[Phase5_E2E_MQTT]
```

### Phase 1 — Structure
1. Delete `stm32/build/`
2. Move NRF probe → `tests/03-nrf/main.c`
3. Create `tests/01–08` + `common/` + master CMakeLists
4. Document CSN rewire PA8→PA4 for motor tests

**Exit:** Each test dir builds (even stub README-only OK for empty tests).

### Phase 2 — Component tests
5–12. Implement tests 01–08 as hardware arrives; RFID parser from v1.

**Exit:** LED/UART/NRF/Motor/Encoder/RFID PASS on bench.

### Phase 3 — Production STM firmware
13. Vendor FreeRTOS from v1 CubeMX tree  
14. `nrf24l01.c` (bit-bang) + `protocol.c` + `crc8.c`  
15. Port `wifeeder.c` loop; `motor`/`encoder`/`rfid`/`hx711`/`flash_int`  
16. Tasks: Radio / Wifeeder / Cmd / Iwdg  

**Exit:** Status heartbeat + RFID→FEED_CMD→FEED_DONE with Pi test harness.

### Phase 4 — Raspberry Pi
17. `nrf_link` replacing walink  
18. Port diet/animal/database(SQLite)/mqtt/main threads  
19. Rebind scale/fwmgr/cli  

**Exit:** Full feed cycle without cloud.

### Phase 5 — E2E
20. MQTT uplink/downlink  
21. 5 min offline + diet GTest from v1  
22. Multi-actuator pipe addressing  

**Exit:** Behavioral contracts in §6 satisfied.

---

## 10. How to Build / Flash / Serial

### Build a test
```bash
cd /home/luceor/Desktop/wifeeder-v2/tests/03-nrf
mkdir -p build && cd build
cmake .. -DCMAKE_TOOLCHAIN_FILE=/home/luceor/Desktop/wifeeder/cmake/toolchain-arm-none-eabi.cmake
cmake --build . -j$(nproc)
```

### Flash
```bash
# Mass storage
cp build/test_nrf.bin /media/luceor/NODE_L432KC/

# OpenOCD via Docker
sg docker -c 'docker run --rm --user root --privileged \
  -v /dev/bus/usb:/dev/bus/usb -v /home/luceor/Desktop/wifeeder-v2:/workspace \
  wifeeder-dev bash -c "
  openocd -f interface/stlink.cfg -f target/stm32l4x.cfg \
    -c \"init\" -c \"program /workspace/tests/03-nrf/build/test_nrf.elf verify reset exit\"
"'
```

### Serial
```bash
# VCP (LPUART1 PA2) typically /dev/ttyACM0
# External PL2303: GREEN=TX→STM RX, WHITE=RX←STM TX
sudo chmod 666 /dev/ttyUSB0
stty -F /dev/ttyUSB0 115200 raw -echo
cat /dev/ttyUSB0
```

Use `-DSTM32L486xx` for HAL compatibility on L432; `-ffunction-sections -fdata-sections` + `-Wl,--gc-sections`.

---

## 11. Risk Register

| Risk | Mitigation |
|---|---|
| NRF module silent on SPI | STATUS=0x0E + RF_CH R/W test; 5V adapter; >10 ms power-on delay |
| PA6 shorted | Always MISO=PB1 |
| Pin starvation on L432 | MVP 1 motor; Phase 3b for M2/HX711/Enc2 |
| CSN vs Motor1 on PA8 | Production CSN=PA4 |
| Dual v1 protocols confuse ports | Map from MCU `T_eMsgType` only; drop walink framing |
| L486 flash pages invalid | New flash map for 256 KB |
| FreeRTOS missing in v2 | Copy from v1 CubeMX Third_Party |
| HARDWARE.md historically wrong | This plan + HARDWARE.md sync are authoritative |

---

## 12. File Inventory — What to Create (code phases)

| File | Type | Content |
|---|---|---|
| `stm32/Core/Inc|Src/*` | FW | Drivers + wifeeder + protocol + FreeRTOS main |
| `stm32/Middlewares/FreeRTOS/` | Vendor | From v1 |
| `tests/01–08/*` | Tests | Standalone bring-up |
| `raspberry/src|include/*` | Host | Ported Host + nrf_link |
| `docs/wifeeder-v2-final-plan.md` | Doc | **This file** |
| `diagrams/PLAN-01` … `PLAN-07` | Diagrams | Roadmap / pins / port / protocol |

---

## 13. Related Docs

| Doc | Role after sync |
|-----|---|
| [`HARDWARE.md`](../HARDWARE.md) | Locked L432KC pin map |
| [`SOFTWARE.md`](../SOFTWARE.md) | TIM1/TIM16/TIM2; FreeRTOS tasks |
| [`PROTOCOL.md`](../PROTOCOL.md) | NRF packet types |
| [`ARCHITECTURE.md`](../ARCHITECTURE.md) | System topology |
| v1 `WIFEEDER_Documentation.md` | Behavioral source of truth |

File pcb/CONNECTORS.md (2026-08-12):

# Actuator carrier connectors (spin 1)

Electrical nets match [`../stm32/Core/Inc/board.h`](../stm32/Core/Inc/board.h).  
This table **replaces breadboard columns** in [`../wiring/CONNECTOR_MAP.md`](../wiring/CONNECTOR_MAP.md) when the PCB is used.

## Mechanical lock

GX aviation series was **not measured**. Spin 1 uses **5.08 mm screw terminals**. Panel GX-12/16 plugs fly-wire ≤ 20 mm to TB3 / TB4. IBT-2 **B+/B−/M+/M−** stay on the module screws; TB2/TB3 are adjacent 16 AWG landing points.

IBT keepout: **50×50 mm** + stock heatsink. Nucleo USB overhangs the **top** edge (~15 mm). NRF antenna keepout: no 12 V / pour under SMA (`Dwgs.User` box).

---

## TB1 — 12 V in

| Pin | Net |
|-----|-----|
| 1 | 12V_IN (pre-fuse) |
| 2 | GND |

## TB2 — to IBT B+/B−

| Pin | Net |
|-----|-----|
| 1 | 12V_SAFE (after fuse + P-FET) |
| 2 | GND |

## TB3 — motor / GX-2 fly-wire

| Pin | Net | GX-2 |
|-----|-----|---|
| 1 | MOTOR_P | pin 1 M+ |
| 2 | MOTOR_N | pin 2 M− |

Tie to IBT **M+/M−** with short 16 AWG (or use IBT screws as the only motor connection).

## TB4 — encoder 4-wire pigtail

Factory encoder cable + plug. Land the four flying leads here (no separate GX-4 + encoder body).

| Pin | Net | Pigtail |
|-----|-----|---|
| 1 | 5V | VCC after meter ID (photo pin colors are 2× red + 2× black) |
| 2 | GND | GND after meter ID |
| 3 | ENC_A (PA0) + 4.7 kΩ to 3V3 | A after meter ID |
| 4 | ENC_B (PA1) + 4.7 kΩ to 3V3 | B after meter ID |

## J_NRF — AM1117 adapter 2×4 (VCC = **5 V**)

| Pin | NRF | MCU |
|-----|-----|-----|
| 1 | GND | GND |
| 2 | VCC | **5V** |
| 3 | CE | PB0 / D3 |
| 4 | CSN | PA4 / A3 |
| 5 | SCK | PA5 / A4 |
| 6 | MOSI | PA7 / A6 |
| 7 | MISO | PB1 / D6 |
| 8 | IRQ | nc |

## J_IBT — logic (2.54 mm)

| Pin | IBT | Net |
|-----|-----|-----|
| 1 | RPWM | PCA PWM0 |
| 2 | LPWM | PCA PWM1 |
| 3 | R_EN | 3V3 |
| 4 | L_EN | 3V3 |
| 5 | R_IS | nc |
| 6 | L_IS | nc |
| 7 | VCC | 5V |
| 8 | GND | GND |

## J_NUC_L / J_NUC_R — Nucleo-32 (Nano 15+15, 0.6")

CN3 (left, USB at top): D13, **3V3**, AREF, A0, A1, A2/PA3 RFID, A3 CSN, A4 SCK, **A5/PA6 NC**, A6 MOSI, A7, 5V (open), NRST, GND, VIN (open).

CN4 (right): D1, D0, NRST, GND, D2, D3 CE, D4 SDA, D5 SCL, D6 MISO, D7, D8, D9, D10, D11 HX711 SCK, D12 HX711 DOUT.

## J_RFID / J_HX711 — JST-XH-4 (DNP)

| J_RFID | Net | J_HX711 | Net |
|---|-----|---|-----|
| 1 VCC | 5V (or 3V3 via SJ_RFID_V) | 1 | 3V3 |
| 2 GND | GND | 2 | GND |
| 3 RX | PA3 | 3 DOUT | PB4 |
| 4 NC | — | 4 SCK | PB5 |

## Test points

TP1 `12V_SAFE` · TP2 `5V` · TP3 `3V3` · TP4 `GND`

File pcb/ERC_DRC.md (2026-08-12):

# ERC / DRC notes (spin 1)

KiCad is not required to *edit* these files, but **zone fill + official DRC** should be run in KiCad 8 before ordering.

## Intentional (exclude in ERC if flagged)

| Item | Why |
|---|-----|
| PA6_NC no-connect | Nucleo PA6 shorted to GND on the module — do not route |
| J_NRF pin 8 (IRQ) nc | Firmware does not use IRQ |
| LED2–15 of PCA9685 unconnected | No Motor2; pads exist for probing |
| J_MINI / SJ_MINI open | Discrete bucks stuffed; Mini360 is fallback |
| NUC_5V, NUC_VIN unconnected by default | Carrier injects **3V3** only; USB unplugged |
| IBT_RIS / IBT_LIS nc | Current-sense unused |
| MOTOR_P/N not tied to IBT pads | IBT M+/M− are module screws; TB3 is GX fly-wire |

## Must pass

- Clearance ≥ 0.2 mm (power ≥ 0.4 mm)
- 12V_SAFE pour does not enter NRF keepout (118,2)–(149,28)
- Nucleo 3V3 and GND each have exactly the intended sockets
- NRF VCC net is **5V**, never 3V3

## Mechanical lock (GX)

Chassis GX-12 / GX-16 series was **not measured** on the bench. Spin 1 uses **5.08 mm Phoenix-style screws** (TB3 motor, TB4 encoder). Panel aviation plugs fly-wire ≤ 20 mm. Revisit footprints if you measure GX12-2 / GX16-4.

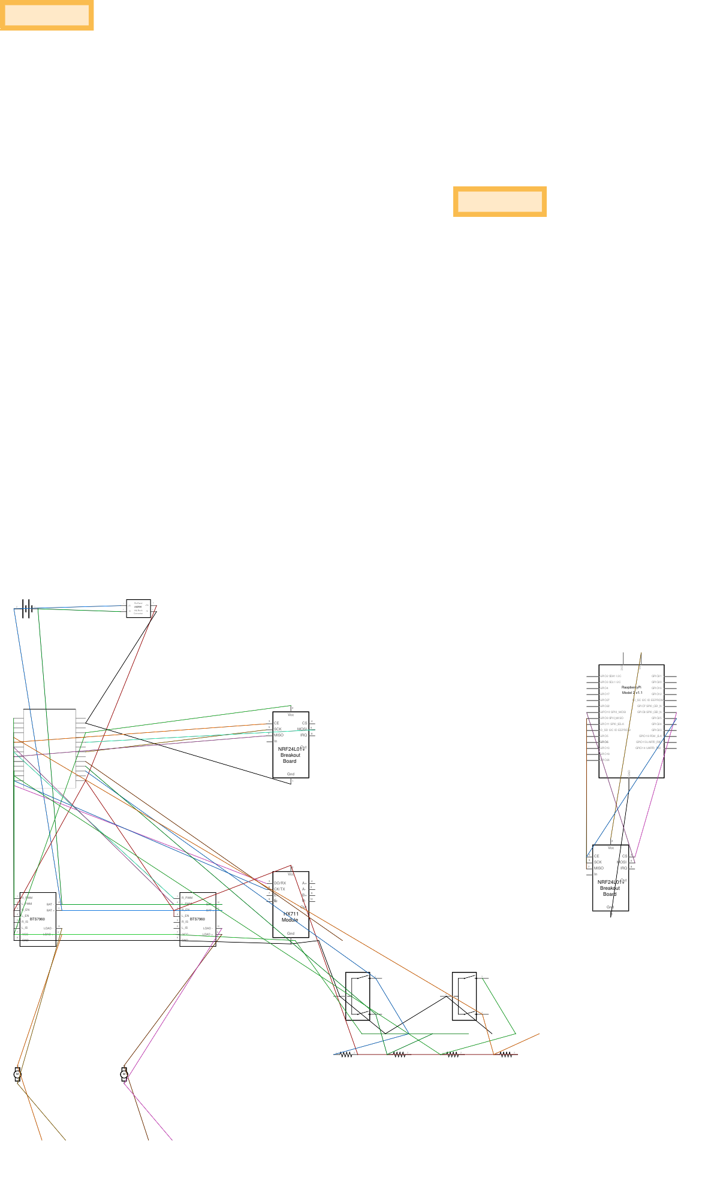
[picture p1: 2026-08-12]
wiring/exports/wifeeder-v2_schematic.png

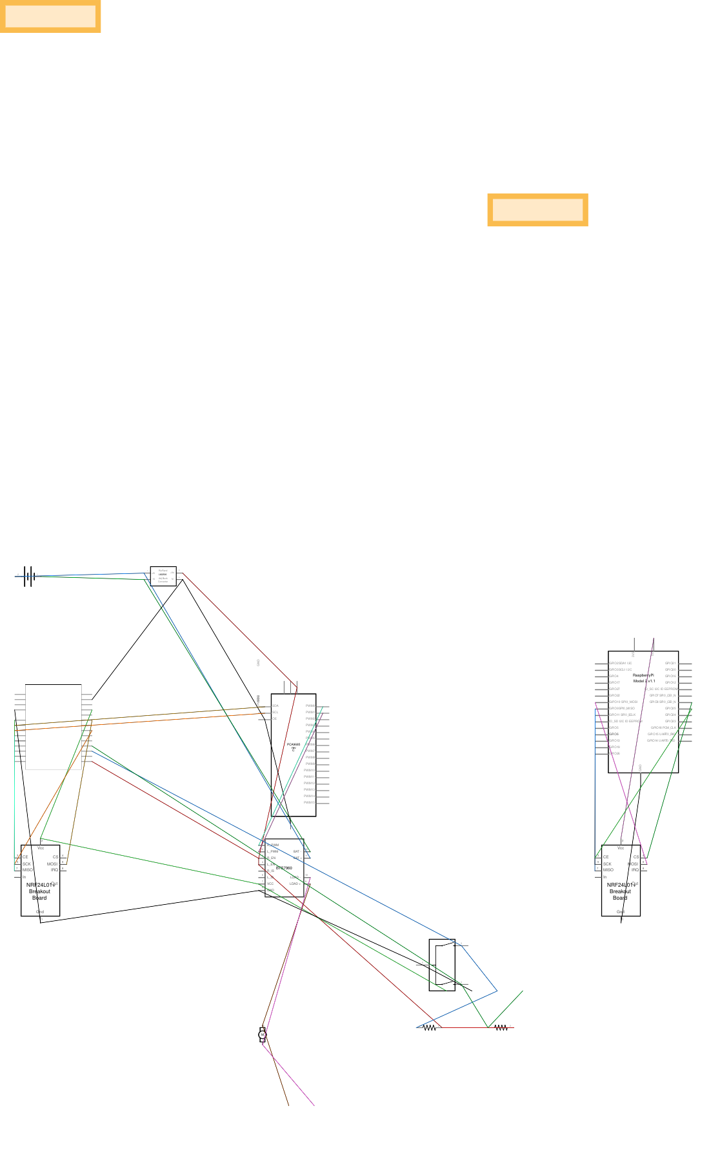
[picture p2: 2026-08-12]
wiring/exports/wifeeder-v2-schematic.png

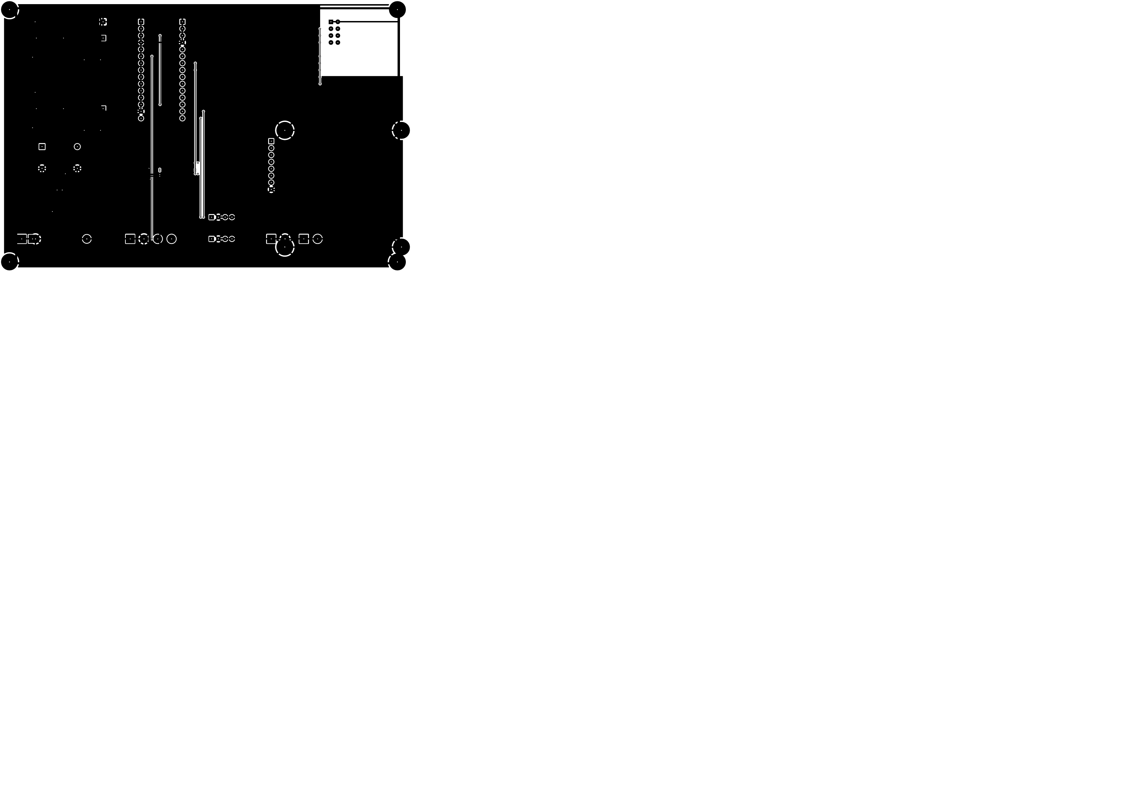
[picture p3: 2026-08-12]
pcb/audit/final-B_Cu-1.png

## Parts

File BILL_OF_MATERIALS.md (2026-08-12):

# WiFeeder v2 — Bill of Materials

---

## 1. Per Station (1 Controller + 1 Actuator)

```mermaid
graph TB
    subgraph Station["One Station"]
        subgraph Pi["Raspberry Pi Controller"]
            R1["Raspberry Pi 3B+ or 4"]
            R2["NRF24L01+ Module"]
            R3["MicroSD Card 32GB"]
            R4["5V 3A USB-C Power"]
            R5["Ethernet or WiFi"]
        end

        subgraph Act["1 Actuator"]
            A1["NUCLEO-L432KC"]
            A2["NRF24L01+ Module"]
            A3["IBT-2 Motor Driver"]
            A4["Mini360 DC-DC Buck"]
            A5["RFID Reader 125kHz"]
            A6["DC Motor with Encoder"]
            A7["DC Motor with Encoder"]
            A8["12V Battery or PSU"]
        end
    end
```

---

## 2. Detailed Materials List

### 2.1 Raspberry Pi Controller (1 per station)

| # | Item | Model/Spec | Qty | Est. Cost (USD) | Source |
|---|---|---|-----|---|---|
| 1 | Raspberry Pi | 3B+ or 4 (2GB+) | 1 | $35-55 | amazon.com, pishop.us |
| 2 | NRF24L01+ Module | nRF24L01+P with antenna | 1 | $2-5 | amazon.com, aliexpress.com |
| 3 | MicroSD Card | 32GB Class 10 A1 | 1 | $8-12 | amazon.com |
| 4 | Power Supply | 5V 3A USB-C | 1 | $10-15 | amazon.com |
| 5 | Jumper Wires | Dupont M-F, 20cm | 1 set | $3-5 | amazon.com |
| 6 | Breadboard | 400-point (optional) | 1 | $3-5 | amazon.com |

**Subtotal Pi**: ~$61-97

### 2.2 STM32 Actuator (per feeding point)

| # | Item | Model/Spec | Qty | Est. Cost (USD) | Source |
|---|---|---|-----|---|---|
| 1 | NUCLEO Board | NUCLEO-L432KC | 1 | $11-15 | st.com, mouser.com, digikey.com |
| 2 | NRF24L01+ Module | nRF24L01+P with antenna | 1 | $2-5 | amazon.com, aliexpress.com |
| 3 | Motor Driver | IBT-2 (BTS7960B) | 1 | $8-15 | amazon.com, aliexpress.com |
| 4 | Actuator PCB | Hybrid carrier ([`pcb/`](pcb/)) | 1 | fab quote | JLCPCB / PCBWay |
| 4a | 5 V / 3.3 V bucks | AP63205 + AP63203 (on PCB) | 1+1 | $2-4 | LCSC / Digi-Key |
| 4b | PCA9685 | TSSOP-28 (on PCB, not breakout) | 1 | $2-4 | LCSC / Adafruit die |
| 4c | Mini360 | DNP fallback only | 0 | — | stuff only if U2 omitted |
| 5 | RFID Reader | 125kHz EM4100 compatible | 1 | $15-30 | amazon.com, aliexpress.com |
| 6 | DC Motor | 12V with encoder (400 PPR) | 2 | $20-40 each | amazon.com, pololu.com |
| 7 | Power Supply | 12V 10A DC or Battery | 1 | $20-50 | amazon.com |
| 8 | Jumper Wires | Dupont M-M, 20cm | 1 set | $3-5 | amazon.com |
| 9 | Breadboard | Bench only (no-PCB bring-up) | 0–1 | $5-10 | amazon.com |
| 10 | Screw Terminals | 2-pin / 4-pin blocks | 5 | $5-8 | amazon.com |

**Subtotal Actuator**: ~$111-223

### 2.3 Optional Components

| # | Item | Model/Spec | Qty | Est. Cost (USD) | Notes |
|---|---|---|-----|---|---|
| 1 | HX711 Module | Load Cell ADC | 1 | $3-5 | For weighing |
| 2 | Load Cell | 50kg or 100kg | 1 | $10-20 | For weighing |
| 3 | NRF24L01+ PA+LNA | High-power version | 1 | $5-10 | For longer range |
| 4 | USB-Serial Adapter | CP2102 or FT232 | 1 | $5-10 | For debug CLI |
| 5 | Multimeter | Digital | 1 | $15-30 | Essential for debugging |
| 6 | Logic Analyzer | 8ch 24MHz | 1 | $10-20 | For signal analysis |
| 7 | Oscilloscope | DSO138 or similar | 1 | $20-40 | For PWM/encoder analysis |

**Subtotal Optional**: ~$68-135

---

## 3. Total Cost Summary

| Configuration | Cost Range |
|---|---|
| **Minimal** (1 Pi + 1 Actuator, no weighing) | **$172-320** |
| **Standard** (1 Pi + 1 Actuator + weighing) | **$185-345** |
| **Full** (1 Pi + 1 Actuator + weighing + tools) | **$253-480** |
| **+ Each additional actuator** | +$111-223 |

Compare to v1 (CAN bus):
| v1 Cost | v2 Cost | Savings |
|---|---|---|
| ~$200-350 per actuator | ~$111-223 per actuator | **~30% cheaper** |

---

## 4. Recommended Suppliers

| Supplier | URL | Best For |
|---|-----|---|
| **STMicroelectronics** | [st.com](https://www.st.com) | NUCLEO boards (official) |
| **Mouser** | [mouser.com](https://www.mouser.com) | Electronic components |
| **DigiKey** | [digikey.com](https://www.digikey.com) | Electronic components |
| **Amazon** | [amazon.com](https://www.amazon.com) | Kits, tools, fast shipping |
| **AliExpress** | [aliexpress.com](https://www.aliexpress.com) | Cheap modules (slower) |
| **Pololu** | [pololu.com](https://www.pololu.com) | Motors with encoders |
| **Adafruit** | [adafruit.com](https://www.adafruit.com) | Modules, tutorials |
| **SparkFun** | [sparkfun.com](https://www.sparkfun.com) | Modules, breakout boards |

---

## 5. Connector Kit (for NUCLEO-L432KC)

```mermaid
graph LR
    subgraph Connectors["Connectors Kit"]
        C1["JST-XH 2.54mm<br/>Power connectors"]
        C2["Dupont Male-Female<br/>Signal wires"]
        C3["Screw Terminals<br/>Motor power"]
        C4["Barrel Jack<br/>12V input"]
        C5["Pin Headers<br/>Breakout"]
        C6["Heat Shrink<br/>Insulation"]
    end

    C1 -->|"For Mini360 and IBT-2"| Use
    C2 -->|"For signal connections"| Use
    C3 -->|"For motor wires (12V/2A)"| Use
    C4 -->|"For 12V power input"| Use
    C5 -->|"For breadboard prototyping"| Use
    C6 -->|"For wire insulation"| Use
```

---

## 6. Tool Checklist

- [ ] Soldering iron (if making permanent connections)
- [ ] Wire stripper/cutter
- [ ] Multimeter (voltage, continuity, resistance)
- [ ] USB Micro-B cable (for NUCLEO programming)
- [ ] MicroSD card reader (for RPi OS installation)
- [ ] Screwdriver set (small flathead and Phillips)
- [ ] Heat shrink tubing + heat gun (or lighter)
- [ ] Electrical tape
- [ ] Tweezers (for small component handling)
- [ ] Magnifying glass or loupe (for small text on PCBs)

---

## 7. Pre-Assembled Kits (Alternative)

For faster deployment, consider pre-assembled kits:

| Kit | Contents | Est. Cost |
|-----|---|---|
| **WiFeeder v2 Starter** | NUCLEO + NRF + IBT-2 + Mini360 + Jumper wires | $50-70 |
| **WiFeeder v2 Complete** | Starter + RFID + 2x Motors + Encoders + PSU | $150-200 |
| **WiFeeder v2 Full** | Complete + HX711 + Load Cell + Tools set | $200-280 |

*(Contact Codintek for custom pre-assembled kits)*

---

## 8. Wiring Harness Diagram

```mermaid
graph TB
    subgraph Box["Actuator Box (one per feeding point)"]
        direction TB
        
        subgraph Top["Top Section (Logic)"]
            NUCLEO["NUCLEO-L432KC"]
            NRF["NRF24L01+"]
            MINI["Mini360 DC-DC"]
            RFID_READER["RFID Reader"]
        end

        subgraph Bottom["Bottom Section (Power)"]
            IBT["IBT-2 Motor Driver"]
            TERM["Terminal Blocks"]
            FUSE["10A Fuse"]
        end

        subgraph External["External Connectors"]
            PWR_IN["12V Power Input"]
            MOTOR1_OUT["Motor 1 Output"]
            MOTOR2_OUT["Motor 2 Output"]
            ENC1_IN["Encoder 1 Input"]
            ENC2_IN["Encoder 2 Input"]
            RFID_IN["RFID Antenna Input"]
            USB_IN["USB Debug Port"]
        end
    end

    PWR_IN --> FUSE
    FUSE --> MINI
    FUSE --> IBT
    MINI --> NUCLEO
    MINI --> NRF
    MINI --> RFID_READER
    NUCLEO --> IBT
    NUCLEO --> NRF
    NUCLEO --> RFID_READER
    IBT --> MOTOR1_OUT
    IBT --> MOTOR2_OUT
    ENC1_IN --> NUCLEO
    ENC2_IN --> NUCLEO
    RFID_IN --> RFID_READER
    USB_IN --> NUCLEO

    style Box fill:#f5f5f5,stroke:#333
    style Top fill:#e8f5e9,stroke:#2e7d32
    style Bottom fill:#fff3e0,stroke:#e65100
```

---

## 9. Ordering Checklist

### Phase 1: Development & Testing (1 station)

- [ ] 1x Raspberry Pi 4 (2GB)
- [ ] 2x NRF24L01+ modules
- [ ] 1x NUCLEO-L432KC
- [ ] 1x IBT-2 motor driver
- [ ] 1x Mini360 DC-DC converter
- [ ] 1x RFID reader (125kHz)
- [ ] 2x DC motors with encoders
- [ ] 1x 12V 10A power supply
- [ ] Jumper wires, breadboard, tools

### Phase 2: Production Rollout (per additional station)

- [ ] 1x NUCLEO-L432KC
- [ ] 1x NRF24L01+ module
- [ ] 1x IBT-2 motor driver
- [ ] 1x Mini360 DC-DC converter
- [ ] 1x RFID reader
- [ ] 2x DC motors with encoders
- [ ] 1x 12V 10A power supply
- [ ] Wiring harness (pre-made)

---

## 10. Sustainability Notes

| Component | Lifespan | Recyclable |
|---|---|---|
| NUCLEO-L432KC | 5+ years | Yes (electronics recycling) |
| NRF24L01+ | 3-5 years | Yes (small PCB) |
| IBT-2 | 5+ years | Yes (electronics recycling) |
| Mini360 | 3-5 years | Yes |
| Motors | 2-5 years (brushes wear) | Yes (metal) |
| RFID Reader | 5+ years | Yes |
| 12V Battery | 2-3 years (lead-acid) | Yes (lead-acid recycling) |
| 12V PSU | 5+ years | Yes |

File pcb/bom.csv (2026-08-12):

Item | Qty | Value | Package | Ref | Notes
1 | 1 | NUCLEO-L432KC | Nano 15+15 socket | J_NUC_L J_NUC_R | Module — do not chip-down
2 | 1 | IBT-2 BTS7960 | 50x50 module | J_IBT TB2 | Logic socket + B+/B- screws
3 | 1 | NRF24 AM1117 adapter | 2x4 2.54 | J_NRF | VCC=5V
4 | 1 | PCA9685 | TSSOP-28 | U3 | Addr 0x40 OE=GND
5 | 1 | AP63205 | SOT-23-6 | U1 | Fixed 5V ~2A
6 | 1 | AP63203 | SOT-23-6 | U2 | Fixed 3.3V ~1A
7 | 2 | 4.7uH 3A | 6x6 | L1 L2
8 | 1 | AO4407A | SOIC-8 | Q1 | Reverse-polarity P-FET
9 | 1 | SMAJ15A | SMA | D1 | TVS 15V
10 | 1 | 10A 5x20 fuse | clips | F1
11 | 4 | 10uF 25V | 1206 | C1 C4 C8
12 | 2 | 22uF 16V | 1206 | C2 C5
13 | 4 | 100nF | 0805 | C3 C6 C7
14 | 2 | 4.7k I2C | 0805 | R6 R7
15 | 2 | 4.7k Enc | 0805 | R4 R5
16 | 1 | 100k | 0805 | R1 | Q1 gate
17 | 2 | 1k | 0805 | R2 R3 | LED
18 | 2 | LED green | 0805 | D2 D3 | 5V / 3V3
19 | 3 | Terminal 5.08 2p |  | TB1 TB2 TB3 | 12V / IBT / motor
20 | 1 | Terminal 5.08 4p |  | TB4 | Encoder GX fly-wire
21 | 2 | JST-XH-4 | DNP | J_RFID J_HX711 | Unpopulated MVP
22 | 1 | Mini360 | DNP | J_MINI | Only if U2 omitted
23 | 8 | M3 hole |  | H1-H8 | Board + IBT
24 | 0 | Mini360 stuffed |  | — | Default not fitted

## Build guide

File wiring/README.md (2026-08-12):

# WiFeeder v2 — Fritzing wiring pack

**Production (less wiring):** hybrid actuator PCB in [`../pcb/`](../pcb/). This Fritzing pack is the **bench / no-PCB** layout.

Main sketch: **[`wifeeder-v2.fzz`](wifeeder-v2.fzz)**  
**Per-block sketches:** [`blocks/`](blocks/) (power, PCA9685, motor, encoder, NRF STM, NRF Pi)  
Pin tables: **[`CONNECTOR_MAP.md`](CONNECTOR_MAP.md)**  
Preview exports: [`exports/wifeeder-v2-breadboard.png`](exports/wifeeder-v2-breadboard.png), [`exports/wifeeder-v2-schematic.png`](exports/wifeeder-v2-schematic.png)

Covers STM32 actuator (Nucleo + PCA9685 + IBT-2 + one motor + one 4-wire encoder pigtail + NRF) and Raspberry Pi host NRF, matching [`../HARDWARE.md`](../HARDWARE.md).

## Install Fritzing (this Linux machine)

**System package (installed):**

```bash
fritzing          # /usr/bin/fritzing  — also in the app menu
```

Packages: `fritzing`, `fritzing-data`, `fritzing-parts` (apt, 0.9.6).

Optional newer binary (not required): `~/Applications/fritzing/Fritzing` from the CD-548 release tarball.

## Open the sketch

1. Open `wiring/wifeeder-v2.fzz` for the full MVP, or a file under `wiring/blocks/` for one island.
2. **Main sketch (bench):** **USB Nucleo** feeds **X=3V3** and **Z=5V**. Mini360 **OUT is off X** until a meter shows 3.30 V (unset pot ≈ 10 V killed the first Nucleo + IBT 74HC244). **Never** put Nucleo/Pi 5 V on NRF VCC.
3. **MVP modules:** PCA9685 (I2C D4/D5) → IBT-2 → **one** motor; **one** encoder; NRF STM + Pi. Battery → IBT B± stays direct.
4. Rebuild all sketches: `python3 wiring/tools/build_wired_sketch.py`
5. Previews: [`exports/wifeeder-v2-breadboard.png`](exports/wifeeder-v2-breadboard.png)

Details: [`CONNECTOR_MAP.md`](CONNECTOR_MAP.md), block index: [`blocks/README.md`](blocks/README.md).

## Rebuild parts / exports

```bash
# Needs Nucleo SVG tree at /tmp/Fritzing-components (or re-clone Blacksocks/Fritzing-components)
# and Fritzing core parts under ~/Applications/fritzing/fritzing-parts
python3 wiring/tools/build_wiring_pack.py
```

## Legend (see also `blocks/`)

**Rule:** one jumper per Nucleo pin; daisy via the breadboard (same X/W/Y/Z + columns on **every** block). PCA right header only (not C2).

| Island | Sketch | Contents |
|---|---|---|
| Power | `blocks/01-power.fzz` | 12 V battery, Mini360 → Nucleo 3V3/GND |
| PWM | `blocks/02-pca9685.fzz` | Nucleo D4/D5 ↔ PCA9685; power/OE from Buck |
| Drive | `blocks/03-motor.fzz` | IBT-2, GX-2 → PN01007BRKT |
| Sense | `blocks/04-encoder.fzz` | 4-wire encoder pigtail; pull-ups on cols 40/41 |
| STM RF | `blocks/05-nrf-stm.fzz` | Nucleo + NRF (**VCC=3.3 V**) |
| Pi RF | `blocks/06-nrf-pi.fzz` | Raspberry Pi + NRF (**VCC=3.3 V pin 1**) |

## Verification checklist

- [ ] Continuity: motor GX-2; encoder **red/black/green/white** ↔ Z / Y / col 40 / col 41
- [ ] NRF VCC ≈ **3.3 V** on STM and Pi (not 5 V)
- [ ] Encoder A/B idle high (~3.3 V) with pull-ups; toggle when shaft turns
- [ ] No wire on **PA6**

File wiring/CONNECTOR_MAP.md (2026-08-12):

# WiFeeder v2 — Connector & pin map (MVP + PCA9685)

Authoritative wiring for [`wifeeder-v2.fzz`](wifeeder-v2.fzz).  
Per-block sketches: [`blocks/`](blocks/).

**MVP scope:** one **PN01007BRKT** motor, one factory-cabled **GTS06** encoder (4 flying leads), **PCA9685** PWM driver, NRF link. Motor2 / Enc2 / HX711 / RFID deferred.

**Bench layout:** the main `.fzz` **and every block** use the **same** breadboard map (rails X/W/Y/Z + columns below). Open one block at a time to wire that island.

---

## Hard rule: one jumper per Nucleo pin

Nucleo header pins accept **exactly one** physical jumper. Do not stack wires on 3V3, 5V, GND, A0, or A1.

| Nucleo pin | Single connection |
|---|---|
| 3V3 | → Breadboard **X** (Nucleo **USB** supplies 3.3 V — do **not** inject Mini360) |
| GND (analog `1001`) | ← Breadboard **W** (GND) |
| GND (digital `1103`) | → NRF GND only |
| 5V | → Breadboard **Z** only (IBT / encoder — **not** NRF) |
| D5 / D4 | → BB cols **30** / **31** (then PCA SCL/SDA) |
| D3 / A3 / A4 / A6 / D6 | → BB cols **45–49** (then NRF SPI) |
| A0 / A1 | ← BB cols **40** / **41** (Enc A/B + pull-ups) |

**Daisy hubs:** breadboard rails (not stacked on Nucleo). Battery → IBT B± stays **direct** (high current).

### What went wrong (2026-08-11) — Mini360 + our old map

The Mini360 is an **adjustable** buck. The pot shipped at ~**10 V**. Our old sketch treated OUT as “3V3” and wired **OUT → rail X → Nucleo 3V3** and **IBT R_EN/L_EN**. That put ~10 V on the STM32 3.3 V rail (smoke) and on the IBT logic pins (74HC244 crater).

**Wiring fault (ours):** using Mini360 as the MCU 3.3 V source with no measure-before-connect.  
**Not a broken Mini360:** set the pot to **3.30 V** and tape it. Do **not** reconnect OUT to X until then.

**New bench rule:** Nucleo **USB** supplies the logic rails. Mini360 **IN** may sit on the battery so you can set the pot; **OUT+ stays off X**.

**Bring-up** (new Nucleo + new IBT; USB first, battery last):

1. Mini360 **alone**: 12 V on IN, meter on OUT. Set **3.30 V**, tape the pot. Leave OUT disconnected.
2. Nucleo **USB only**. Meter: **3V3 = 3.3 V**, **5V ≈ 4.8 V**.
3. **Nucleo 3V3 → X**, **5V → Z**, **GND → W**, **W↔Y**. Meter X and Z before anything else.
4. IBT **VCC** (silk) → **Z**, **GND** → **W**. Meter the IBT VCC pin. **B+ still open.**
5. PCA VCC → **X** (right header, not V+/C2). EN → **X**. Encoder on Z/Y/40/41.
6. **Last:** fused battery → IBT **B±** only.

If **X** or **Z** is ever > 5.5 V, kill power. Do not reuse the smoked Nucleo or the holed IBT.

---

## Breadboard hub map (main + every `blocks/0N-*.fzz`)

Fritzing **Generic Bajillion Hole** part:

| Rail / column | Net |
|---|-----|
| **X** | 3V3 (**from Nucleo 3V3 / USB**) — NRF VCC, PCA, EN, pull-ups |
| **W** | GND (from Nucleo GND) |
| **Y** | GND (jumpered to W) |
| **Z** | 5V (from Nucleo 5V once) — IBT logic + encoder **only** |
| Col **30** | I2C SCL (Nucleo D5 ↔ PCA SCL) |
| Col **31** | I2C SDA (Nucleo D4 ↔ PCA SDA) |
| Col **33** | PWM0 → IBT RPWM |
| Col **34** | PWM1 → IBT LPWM |
| Col **40** | Enc A + pull-up + Nucleo A0 |
| Col **41** | Enc B + pull-up + Nucleo A1 |
| Col **45** | NRF CE |
| Col **46** | NRF CSN |
| Col **47** | NRF SCK |
| Col **48** | NRF MOSI |
| Col **49** | NRF MISO |

Pi ↔ NRF is a **separate** breadboard (`06-nrf-pi.fzz`) with the **same column numbers** (45–49). Pi pin 1 feeds rail **X**; never pin 2/4.

---

## Why PCA9685

Direct TIM PWM on the Nucleo crowded the headers. **PCA9685** drives IBT-2 RPWM/LPWM so the MCU only needs **SCL + SDA**.

Use the **right logic header** only. Never wire the C2 electrolytic pads (`connector7` / `connector8`).

| Nucleo | MCU | via BB | PCA9685 (right header) |
|---|-----|---|---|
| **D5** | **PB6** I2C1_SCL | col 30 | SCL `connector46` |
| **D4** | **PB7** I2C1_SDA | col 31 | SDA `connector45` |
| — | — | rail X | VCC `connector44` |
| — | — | rail W | GND `connector48` |
| — | — | rail W | **OE `connector47`** |

PCA9685 address: default `0x40` (A0–A5 open).

| PCA9685 ch | via BB | → IBT-2 |
|---|---|---|
| **PWM0** | col 33 | RPWM (M1) |
| **PWM1** | col 34 | LPWM (M1) |

IBT-2 **R_EN** and **L_EN** tied to breadboard **3V3 (X)** (not Nucleo 3V3).

---

## Motor GX-2 (IBT-2 M+/M− → PN01007BRKT)

| GX pin | Net |
|---|-----|
| 1 | M+ |
| 2 | M− |

## Encoder — one 4-wire pigtail (already on the encoder)

The bench encoder is **not** a separate GTS06 body plus a loose GX-4. It arrives as one assembly: encoder + cable + plug, with **four flying leads** on the mating pigtail (photo 2026-08-11).

**Do not use wire color to pick VCC / GND / A / B.** The pigtail is **two red + two black** hookup wires. Identify by the **molded pin numbers** on the plug (solder-cup side in the photo), then confirm with a meter.

| Molded pin (photo) | Pigtail color | Function | Breadboard |
|---|---|---|---|
| **1** | Black | **measure** (not color) | — |
| **2** | Red | **measure** | — |
| **3** | Red | **measure** | — |
| **4** | Black | **measure** | — |

After the meter check, land:

| Net | Breadboard |
|-----|---|
| VCC | rail **Z** (5 V) |
| GND | rail **Y** |
| Phase A | col **40** → **PA0 / A0** |
| Phase B | col **41** → **PA1 / A1** |

**Identify (do this once, then label the four wires):**

1. **Best:** unplug the pigtail. On the encoder-side cable the factory GTS06 colors are usually **red = VCC**, **black = GND**, **green = A**, **white = B** (some sellers swap green/white). Continuity from each pigtail pin to those colors. Write the map on the plug.
2. **Only the 4 leads:** mark them P1–P4 from the molded numbers. Find VCC–GND with a DMM (lowest resistance pair, often a few hundred Ω to a few kΩ, polarity-sensitive). Confirm by applying **5 V through a 470 Ω–1 kΩ series resistor** — the encoder should draw ~10–30 mA. If current is ~0, wrong pair; if >50 mA, disconnect. The other two wires are A and B: 4.7 kΩ to 3V3 each, rotate the shaft, both must toggle. Swap A/B if TIM2 counts the wrong way.

**NPN OC:** 4.7 kΩ pull-ups on BB cols **40/41** → rail **X** (3V3). Do not stack a second jumper on Nucleo A0/A1. There is **no** fifth “C / index” wire.

---

## NUCLEO-L432KC (MVP)

| Label | MCU | Destination |
|---|-----|---|
| **5V** | — | BB **Z** only (IBT / Enc). **Do not** feed NRF |
| GND | — | BB **W** only |
| GND (D-side) | — | NRF GND only |
| **3V3** | — | → BB **X** (Nucleo USB is the source). NRF VCC from **X** |
| D5 | PB6 | BB col 30 → PCA **SCL** |
| D4 | PB7 | BB col 31 → PCA **SDA** |
| D3 | PB0 | BB col 45 → NRF CE |
| A3 | PA4 | BB col 46 → NRF CSN |
| A4 | PA5 | BB col 47 → NRF SCK |
| A6 | PA7 | BB col 48 → NRF MOSI |
| D6 | PB1 | BB col 49 → NRF MISO |
| A0 / A1 | PA0 / PA1 | BB cols 40 / 41 (Enc) |
| **A5** | **PA6** | **Do not use** (shorted) |

Freed vs old map: **PA8/PA9** no longer drive the motor (PWM is on PCA9685).

---

## IBT-2 (single channel / one BTS7960 half of dual board)

| IBT-2 | Connects to |
|---|---|
| B+ / B− | 12 V battery (**direct**, not via BB) |
| R_EN, L_EN | BB **X** (3.3 V) |
| RPWM / LPWM | BB cols **33** / **34** ← PCA PWM0/1 |
| VCC | BB **Z** (5V) |
| GND | BB **W** |
| M+ / M− | GX-2 → motor |
| 5V OUT | unused in BB layout (encoder uses rail Z) |

---

## Raspberry Pi ↔ NRF (unchanged)

| NRF | Pi |
|-----|-----|
| VCC | pin **1 (3.3 V)** — never pin 2/4 5 V on module VCC |
| GND | 6 |
| SCK/MOSI/MISO/CSN/CE | 23 / 19 / 21 / 24 / 22 (GPIO25) |

---

## Power (breadboard hubs — not Nucleo stacking)

1. Nucleo **USB** on. **3V3 → X**, **5V → Z**, **GND → W**; jumper **W↔Y**  
2. Battery → IBT **B±** only (high current off the BB). Mini360 **IN** may share that battery so you can set the pot.  
3. **Mini360 OUT+ is not on X** until a meter reads **3.30 V** (then you may jumper OUT→X and unplug USB for battery-only 3.3 V)  
4. BB **X** → PCA VCC, IBT EN, pull-ups, NRF VCC  
5. BB **W/Y** → PCA GND/OE, IBT GND, encoder GND  
6. BB **Z** → IBT VCC / Enc VCC (**not** NRF)

### Hard rule: NRF VCC = 3.3 V

Nucleo **5V** is ~4.8 V. nRF24L01+ abs max is **3.6 V**. 5 V on module VCC kills PA/LNA permanently; SPI still reads `STATUS=0x0E` (see Aug 2026 bench report). Do not use 5 V “because AM1117” unless you have **measured 3.3 V on the chip VCC pin**.

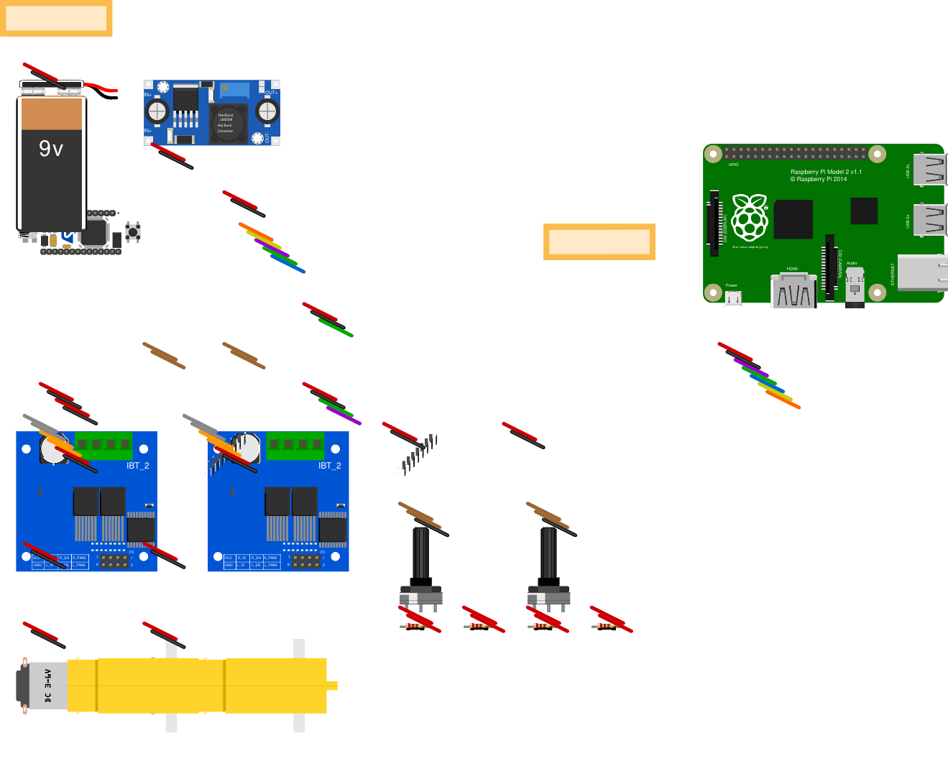
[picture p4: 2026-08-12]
wiring/exports/wifeeder-v2_breadboard.png

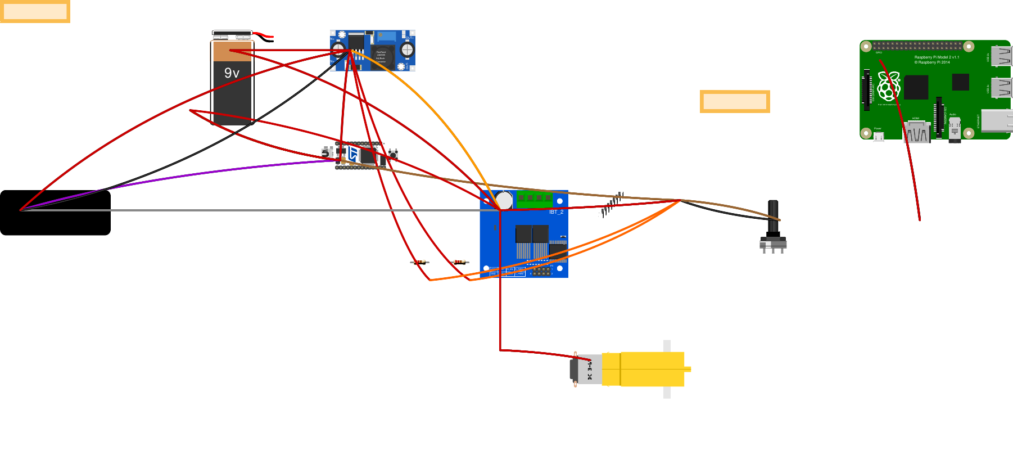
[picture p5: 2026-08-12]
wiring/exports/blocks/wifeeder-v2-breadboard.png

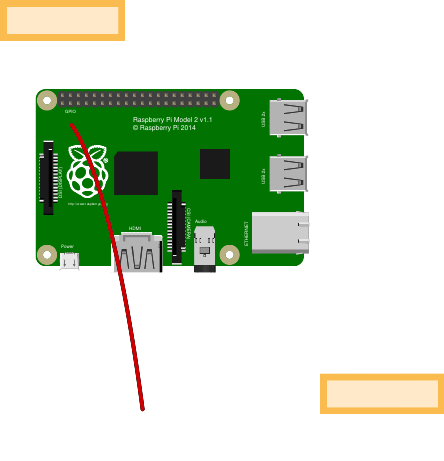
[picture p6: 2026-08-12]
wiring/exports/blocks/06-nrf-pi-breadboard.png

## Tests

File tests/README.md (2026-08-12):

# WiFeeder v2 — Hardware Test Suite

Standalone bring-up programs for **NUCLEO-L432KC** (STM32L432KC) and **Raspberry Pi** NRF link. Each STM32 test is self-contained bare-metal code (register-level where possible) with its own `CMakeLists.txt`.

Authoritative pin map: [`wiring/CONNECTOR_MAP.md`](../wiring/CONNECTOR_MAP.md) · production firmware: [`stm32/Core/Inc/board.h`](../stm32/Core/Inc/board.h).

## Test index

| # | Directory | Target | Purpose |
|---|---|---|---|
| 01 | `01-led/` | `test_led.elf` | PB3 onboard LED blink |
| 02 | `02-uart/` | `test_uart.elf` | USART1 PA9 @ 115200 |
| 03 | `03-nrf/` | `test_nrf.elf` | NRF24 SPI (CSN=**PA4**, CE=PB0) |
| 04 | `04-motor/` | `test_motor.elf` | PCA9685 I2C → IBT-2 (PWM0/1) |
| 05 | `05-encoder/` | `test_encoder.elf` | TIM2 encoder PA0/PA1 |
| 06 | `06-rfid/` | `test_rfid.elf` | USART2 PA3 RFID `$A0112OKD` |
| 07 | `07-hx711/` | `test_hx711.elf` | HX711 bit-bang PB4/PB5 |
| 08 | `08-nrf-pi/` | `test_nrf_tx` / `test_nrf_rx` | Pi spidev + GPIO25 CE |
| 09 | `09-nrf-link/` | `test_nrf_link_stm` + `test_nrf_link` | STM32 ↔ Pi PING/PONG (**CH 76**) |
| 10 | `10-nrf-rf/` | `test_nrf_rf_carrier` / `test_nrf_rf_rpd` | RF energy (CONT_WAVE / RPD) |

Future unit tests (diet GTest ports) live under `tests/unit/`.

## Locked pin map (MVP production)

| Function | Pin | Notes |
|---|-----|---|
| LED | **PB3** | Nucleo LD3 |
| Debug UART | **PA2** | LPUART1 → ST-Link VCP |
| NRF SCK / MOSI / MISO | PA5 / PA7 / **PB1** | Bit-bang SPI; never PA6 |
| NRF CSN / CE | **PA4** / PB0 | **VCC=3.3 V** — never Nucleo 5V |
| PCA9685 SCL / SDA | **PB6** / **PB7** | I2C bit-bang (D5/D4) |
| Motor1 | PCA **PWM0/PWM1** → IBT RPWM/LPWM | EN→3.3V; OE→GND |
| Encoder 1 A/B | **PA0** / **PA1** | TIM2 ×4; 4-wire pigtail (green/white); **600 P/R** |
| RFID RX | **PA3** | USART2 — deferred in MVP wiring |
| HX711 DOUT / SCK | **PB4** / **PB5** | Deferred in MVP wiring |

**Board notes:** PA6 shorted — never use as MISO. One jumper per Nucleo pin (power daisy from Buck/NRF). Motor2 TIM16 on PB6/PB7 is **retired** for MVP.

## Shared build infrastructure

- `cmake/stm32_test.cmake` — CPU flags, `STM32L486xx`, startup, linker, `.bin` post-build
- `common/test_utils.c` — LED PB3 helpers, `delay_ms`, `blink_pattern`
- Startup: `stm32/startup/startup_stm32l486xx.s`
- Linker: `stm32/linker/STM32L432KC_FLASH.ld`

## Build an STM32 test

```bash
cd tests/04-motor
mkdir -p build && cd build
cmake .. -DCMAKE_TOOLCHAIN_FILE=/home/luceor/Desktop/wifeeder/cmake/toolchain-arm-none-eabi.cmake
cmake --build . -j$(nproc)
```

Outputs: `test_motor.elf`, `test_motor.bin`.

## Flash

**Mass storage:** copy `.bin` to `NODE_L432KC` drive.

**OpenOCD (Docker):**

```bash
sg docker -c 'docker run --rm --user root --privileged \
  -v /dev/bus/usb:/dev/bus/usb -v /home/luceor/Desktop/wifeeder-v2:/workspace \
  wifeeder-dev bash -c "
  openocd -f interface/stlink.cfg -f target/stm32l4x.cfg \
    -c \"init\" -c \"program /workspace/tests/04-motor/build/test_motor.elf verify reset exit\"
"'
```

## Serial debug

```bash
# LPUART1 PA2 (ST-Link VCP) — typically /dev/ttyACM0
stty -F /dev/ttyACM0 115200 raw -echo
cat /dev/ttyACM0
```

Test 02 uses **USART1 TX on PA9** with an external USB–serial adapter instead.

## Recommended bench order

1. **01-led** — power & clock
2. **02-uart** — serial sanity
3. **03-nrf** — SPI register R/W (**VCC=3.3 V**)
4. **10-nrf-rf** then **09-nrf-link** — energy then PING/PONG (**CH 76**)
5. **04-motor** (PCA9685) → **05-encoder**
6. **06-rfid** / **07-hx711** when those peripherals are wired

## Phase gate

Component tests PASS on hardware before claiming E2E feed. Production MCU is a bare-metal superloop in `stm32/Core/Src/wifeeder.c` (FreeRTOS later).

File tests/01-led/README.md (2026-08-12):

# Test 01 — LED (PB3)

## Purpose

Verify the NUCLEO-L432KC boots and GPIO works. No external wiring.

## Wiring

| Signal | NUCLEO pin | Notes |
|---|---|---|
| LED LD3 | **PB3** | Onboard green LED |

## Expected behavior

Green LED blinks **2 s ON / 2 s OFF** continuously.

## Build

```bash
cd tests/01-led
mkdir -p build && cd build
cmake .. -DCMAKE_TOOLCHAIN_FILE=/home/luceor/Desktop/wifeeder/cmake/toolchain-arm-none-eabi.cmake
cmake --build .
```

Output: `test_led.elf`, `test_led.bin`

## Flash

Copy `test_led.bin` to the ST-Link mass-storage drive (`NODE_L432KC`) or use OpenOCD (see `tests/README.md`).

## Pass criteria

LED blinks at ~2 s period with no external connections.

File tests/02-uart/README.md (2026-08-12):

# Test 02 — UART debug

## Purpose

Verify serial output. Uses **USART1 TX on PA9** at **115200 8N1** with **HSI 16 MHz** (register-level, no HAL).

Production debug uses **LPUART1 on PA2** (ST-Link VCP). This test uses an external USB–serial adapter on **PA9** for a clear loopback-free check.

## Wiring

| Signal | NUCLEO pin | Arduino | Adapter |
|---|---|---|---|
| USART1 TX | **PA9** | D8* | RX (white) |
| GND | GND | — | GND |

\*On NUCLEO-L432KC Arduino silkscreen, **D9 = PA8**; PA9 is the adjacent pin used here as USART1 TX.

Optional: onboard LED **PB3** blinks briefly each message.

## Expected output

Every **5 seconds**:

```
=== NUCLEO-L432KC UART OK ===
```

## Serial terminal

```bash
sudo chmod 666 /dev/ttyUSB0   # or ttyACM0 if using PA2/LPUART in other tests
stty -F /dev/ttyUSB0 115200 raw -echo
cat /dev/ttyUSB0
```

## Build

```bash
cd tests/02-uart
mkdir -p build && cd build
cmake .. -DCMAKE_TOOLCHAIN_FILE=/home/luceor/Desktop/wifeeder/cmake/toolchain-arm-none-eabi.cmake
cmake --build .
```

## Pass criteria

Repeating banner on serial monitor at 115200 baud.

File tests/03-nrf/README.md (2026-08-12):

# Test 03 — NRF24L01+ SPI bring-up

## Purpose

Verify the NRF24L01+ responds to bit-bang SPI. Prints results on **USART1 PA9 @ 115200**.

## Wiring (current bench)

| NRF pin | STM32 | Notes |
|---|---|---|
| VCC | **3.3 V** | **Never 5 V** — Nucleo 5V (~4.8 V) destroys PA/LNA; SPI may still work |
| GND | GND | Common ground |
| CE | **PB0** | |
| CSN | **PA4** | Production pin |
| SCK | **PA5** | |
| MOSI | **PA7** | |
| MISO | **PB1** | Do not use PA6 |
| IRQ | nc | |

UART debug: **PA9** → USB-serial RX (typically `/dev/ttyUSB0` at 115200).

## LED codes

| Pattern | Meaning |
|---|---|
| ON 5s / OFF 1s | **PASS** — STATUS=0x0E, RF_CH=0x4C |
| ON 3s / OFF 1s | Partial — STATUS OK, RF_CH bad |
| ON 2s / OFF 2s | FAIL — no SPI (0xFF) |

## Build / flash

```bash
cd tests/03-nrf && mkdir -p build && cd build
cmake .. -DCMAKE_TOOLCHAIN_FILE=/home/luceor/Desktop/wifeeder/cmake/toolchain-arm-none-eabi.cmake
cmake --build .
cp test_nrf.bin /media/$USER/NODE_L432KC/
```

Serial:

```bash
stty -F /dev/ttyUSB0 115200 raw -echo
cat /dev/ttyUSB0
```

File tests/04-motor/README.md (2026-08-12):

# Test 04 — IBT-2 motor PWM

## Purpose

Verify Motor1 PWM and direction GPIO on the IBT-2 H-bridge driver.

## Prerequisites

- **Disconnect NRF CSN from PA8** or rewire CSN to **PA4** before this test (PA8 is Motor1 PWM).
- Tie both enable pins to 3.3V (no spare EN GPIO on L432 MVP).

## Wiring — IBT-2 Motor 1

| IBT-2 pin | NUCLEO | Function |
|---|---|---|
| RPWM | **PA8** | TIM1_CH1 PWM @ **10 kHz** |
| LPWM | **PA9** | Direction GPIO |
| R_EN | **3.3V** | Tied high |
| L_EN | **3.3V** | Tied high |
| VCC | 12V (bench supply) | Motor power |
| GND | GND | Common ground |
| M+ / M− | Motor | |

Clock: **HSI 16 MHz**. TIM1: **PSC=15**, **ARR=99** → 10 kHz PWM. Duty ~70% during each 2 s phase.

## Expected behavior

- Motor runs ~2 s one direction, ~2 s reversed (direction toggles on PA9).
- LED **PB3** double-blinks at each direction change.

## Build

```bash
cd tests/04-motor
mkdir -p build && cd build
cmake .. -DCMAKE_TOOLCHAIN_FILE=/home/luceor/Desktop/wifeeder/cmake/toolchain-arm-none-eabi.cmake
cmake --build .
```

## Pass criteria

Audible/visible motor motion with direction reversal; no runaway if EN tied correctly.

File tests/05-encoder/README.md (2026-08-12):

# Test 05 — Encoder (TIM2)

## Purpose

Verify quadrature encoder interface on Encoder 1 (**600 P/R**, TIM2 ×4).

## Wiring

Factory 4-wire pigtail (no separate GX-4). Pull-ups 4.7 kΩ A/B → 3V3 on the breadboard.

Pigtail is **2× red + 2× black** — identify nets by molded pin + meter ([`wiring/CONNECTOR_MAP.md`](../../wiring/CONNECTOR_MAP.md)), then:

| Encoder net | NUCLEO / rail | Timer |
|---|---|---|
| A | **PA0** (A0) via BB col 40 | TIM2_CH1 |
| B | **PA1** (A1) via BB col 41 | TIM2_CH2 |
| VCC | BB **Z** 5 V | — |
| GND | BB **Y** | — |

## Expected behavior

Rotate the encoder shaft: each count change causes a short **PB3** LED blink. TIM2 free-runs as 16-bit counter.

## Build

```bash
cd tests/05-encoder
mkdir -p build && cd build
cmake .. -DCMAKE_TOOLCHAIN_FILE=/home/luceor/Desktop/wifeeder/cmake/toolchain-arm-none-eabi.cmake
cmake --build .
```

## Pass criteria

LED blinks when A/B quadrature edges occur; counter increments/decrements with rotation direction.

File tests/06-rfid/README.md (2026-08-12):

# Test 06 — 134 kHz RFID reader

## Purpose

Verify USART2 RX and parse 27-byte ASCII frames from the v1 134 kHz reader protocol.

## Frame format

27-byte ASCII: `$A0112OKD` + 15-digit decimal tag + 2-digit XOR checksum (hex nibbles).

Checksum: start with `'A'`, XOR bytes `[2..23]`, compare to hex digits at `[24..25]`.

Ported from v1 `MCU/Drivers/RfId/Src/rfid_134khz.c`.

## Wiring

| Reader | NUCLEO | UART |
|---|---|---|
| TX (data out) | **PA3** (USART2_RX) | 9600 8N1 |
| GND | GND | |
| VCC | Per reader spec | Often 5V |

## Expected behavior

On valid tag read:
1. Short LED blinks encode tag ID bits (MSB first).
2. Three long blinks (500 ms) confirm successful parse.

## Build

```bash
cd tests/06-rfid
mkdir -p build && cd build
cmake .. -DCMAKE_TOOLCHAIN_FILE=/home/luceor/Desktop/wifeeder/cmake/toolchain-arm-none-eabi.cmake
cmake --build .
```

## Pass criteria

Present a known tag; LED pattern repeats for each valid frame with correct checksum.

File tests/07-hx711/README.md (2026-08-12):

# Test 07 — HX711 load cell

## Purpose

Verify bit-bang read of 24-bit HX711 data on **PB4/PB5** (not PC0/PC1 — those pins do not exist on L432KC).

## Wiring

| HX711 | NUCLEO | Notes |
|---|---|---|
| DOUT | **PB4** | Input |
| SCK | **PB5** | Output |
| VCC / GND | 3.3V / GND | |
| E+ / E− / A+ / A− | Load cell | Per cell wiring |

## Expected behavior

- Polls HX711 when DOUT goes low.
- On significant weight change (>5000 counts), LED blinks **1–15** times based on magnitude.

## Build

```bash
cd tests/07-hx711
mkdir -p build && cd build
cmake .. -DCMAKE_TOOLCHAIN_FILE=/home/luceor/Desktop/wifeeder/cmake/toolchain-arm-none-eabi.cmake
cmake --build .
```

## Pass criteria

Apply load to cell; LED blink count changes with weight steps.

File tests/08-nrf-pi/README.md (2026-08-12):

# Test 08 — NRF24L01+ on Raspberry Pi 2 Model B

## Purpose

Pi-side SPI bring-up. Code uses **BCM** GPIO numbers (`/dev/spidev0.0` + sysfs **GPIO25**).

## Warning: ignore WiringPi / Pi4J pinout images

Many Google diagrams (including Pi4J) label pins as `GPIO 25` meaning **WiringPi pin 25**, **not** Broadcom BCM 25.

| Scheme | “GPIO 25” means | Physical pin |
|---|---|---|
| **BCM** (Linux, our code, `raspi-gpio`) | BCM 25 | **22** |
| **WiringPi / Pi4J** (that Google image) | WiringPi 25 | **37** (= BCM 26!) |

Same trap on SPI labels in that image (`GPIO 12 MOSI` = WiringPi 12 = physical 19 = **BCM 10**).

**Always wire by physical header pin number (1–40).** Those never change.

## Wiring (physical pins only) — Pi 2 Model B 40-pin

```
NRF pin     →  Pi header pin     (BCM, for reference)
────────────────────────────────────────────────────
VCC         →  pin 1 (3.3V)      NEVER pin 2/4 — 5V kills PA/LNA
GND         →  pin 6  (GND)
MOSI        →  pin 19            (BCM 10)
MISO        →  pin 21            (BCM 9)
SCK         →  pin 23            (BCM 11)
CSN         →  pin 24            (BCM 8 = SPI0 CE0 → /dev/spidev0.0)
CE          →  pin 22            (BCM 25)   ← NOT pin 37
IRQ         →  leave open
```

| NRF | Header pin | Notes |
|-----|---|---|
| VCC | **1** | **3.3 V** — never 5 V on module VCC |
| GND | **6** | |
| MOSI | **19** | |
| MISO | **21** | |
| SCK | **23** | |
| CSN | **24** | must be `spidev0.0` |
| CE | **22** | BCM 25 — **not** pin 37 |

Pin **37** is BCM **26** — do not use for CE with this test.

## Problem we hit: only `/dev/spidev0.1`

v1 **MCP2515 CAN** overlay stole SPI CE0 and GPIO25. Comment out in `/boot/config.txt`:

```
# dtoverlay=mcp2515-can0,...
# dtoverlay=spi-bcm2835-overlay
```

Keep `dtparam=spi=on`, then `sudo reboot`. Confirm:

```bash
ls /dev/spidev0.0
```

## Get code / build / run

```bash
# on PC
scp -r wifeeder-v2/tests/08-nrf-pi pi@<ip>:~/

# on Pi
cd ~/08-nrf-pi
mkdir -p build
g++ -std=c++17 -O2 -Wall -o build/test_nrf_tx test_nrf_tx.cpp
g++ -std=c++17 -O2 -Wall -o build/test_nrf_rx test_nrf_rx.cpp
sudo ./build/test_nrf_tx
```

### Pass / fail

| Output | Meaning |
|---|---|
| `PASS: NRF SPI OK` + `RF_CH=0x4C` | Good |
| `STATUS=0xFF` | MISO open / wrong wire |
| `STATUS=0x00` `RF_CH=0x00` | No chip response — check 3.3V, pins 19/21/23/24, CE on **22** |

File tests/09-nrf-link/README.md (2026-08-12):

# Test 09 — STM32 ↔ Raspberry Pi NRF24 link

## Purpose

End-to-end radio test: **Pi sends `PING`, STM32 replies `PONG`**.

| Side | Role |
|---|---|
| STM32 (`stm32/`) | RX peer — listen forever, reply to each PING |
| Pi (`pi/`) | TX client — send N PINGs, count PONGs |

Radio params (both sides) — production ESB:
- Channel **76** (`0x4C`) — matches `PROTOCOL.md` / prod firmware
- Address **`0xE7E7E7E7E7`**
- **1 Mbps**, max power (`RF_SETUP=0x07`), **8-byte** payload (link test)
- **Auto-ACK on** (`TX_DS` ⇒ peer heard us; `MAX_RT` ⇒ no RF)

Lab note: some SI24R1 clones behave better on channel **64**; use `sweep` only for diagnosis — production default remains **76**.

SPI-OK does not imply RF-OK. Start at **≥10 cm** with antennas attached.

## Bring-up checklist (before claiming PASS)

- [ ] **VCC = 3.3 V** on STM and Pi (Buck / Pi pin 1). **Never** Nucleo or Pi 5 V on module VCC — that is ~4.8 V and permanently kills PA/LNA while SPI still looks OK.
- [ ] Antennas attached on both modules
- [ ] Modules ≥10 cm apart; shared GND if co-located supplies
- [ ] Test **10** carrier/RPD sees energy on CH 76
- [ ] Then test **09** PING/PONG
- [ ] Both sides RF_CH readback = 76

## Wiring

### STM32 (same pins as test 03)

| NRF | Nucleo-32 label | MCU |
|-----|---|-----|
| **VCC** | **3.3 V** (Buck / BB X) | Never Nucleo **5V** (~4.8 V) |
| GND | GND | — |
| CE | **D3** | PB0 |
| CSN | **A3** | PA4 |
| SCK | A4 | PA5 |
| MOSI | A6 | PA7 |
| MISO | D6 | PB1 |

### Pi 2 Model B (physical pins)

| NRF | Header pin |
|-----|---|
| **VCC** | **1 (3.3 V)** — never pin 2/4 (5 V) on module VCC |
| GND | 6 |
| MOSI | 19 |
| MISO | 21 |
| SCK | 23 |
| CSN | 24 (`/dev/spidev0.0`) |
| CE | **22** (BCM GPIO25) |

Need `/dev/spidev0.0` (disable MCP2515 CAN overlay — see `tests/08-nrf-pi/README.md`).

**Do not** put 5 V on module VCC. SPI can still look fine (`STATUS=0x0E`) after the PA/LNA is already dead.
## 1. Build & flash STM32

```bash
cd tests/09-nrf-link/stm32
mkdir -p build && cd build
cmake .. -DCMAKE_TOOLCHAIN_FILE=/home/luceor/Desktop/wifeeder/cmake/toolchain-arm-none-eabi.cmake
cmake --build .

openocd -f interface/stlink.cfg -f target/stm32l4x.cfg \
  -c "init" -c "program test_nrf_link_stm.elf verify reset exit"
```

STM32 LED: 3 short blinks at boot, then a short blink on each answered PING.

### OpenOCD probe cells (after ~1 s run)

| Address | Meaning |
|---|---|
| `0x20000000` | `0xA55A0009` listening; `0xDEAD0001` SPI/init fail |
| `0x20000004` | `(CONFIG<<16)\|(RF_SETUP<<8)\|RF_CH` — expect RF_CH **76** (`0x4C`) |
| `0x20000008` | RX-loop counter (should climb) |
| `0x2000000C` | `pings \| (pongs<<8) \| (rxany<<16)` |

```bash
openocd -f interface/stlink.cfg -f target/stm32l4x.cfg \
  -c "init" -c "halt" -c "mdw 0x20000000 4" -c "resume" -c "shutdown"
```

## 2. Build & run Pi

```bash
scp -r tests/09-nrf-link/pi pi@<ip>:~/09-nrf-link-pi
# on Pi:
cd ~/09-nrf-link-pi
g++ -std=c++17 -O2 -Wall -o test_nrf_link test_nrf_link.cpp
sudo ./test_nrf_link          # 10 rounds
sudo ./test_nrf_link 20       # 20 rounds
sudo ./test_nrf_link sweep    # hunt channel if crystal skew suspected
```

Each PING prints `[ACK TX_DS]` (STM heard the PING) or `[MAX_RT no peer]` (no RF to STM).

## Pass / fail

| Output | Meaning |
|---|---|
| `PASS: STM32 <-> Pi NRF link OK` | ACK + PONG |
| `PARTIAL` + `ACK` | RF OK, PONG path flaky |
| `MAX_RT` every time | No RF at STM — see below |
| Local `FAIL: local NRF config mismatch` | Fix Pi wiring (test 08) |
| STM magic `0xDEAD0001` | Fix STM SPI (test 03) |

### If every PING is `MAX_RT` (lab symptom with PA+LNA adapters)

STM probe should look like:
- `0x20000000` = `0xA55A0009` (listening)
- `0x20000004` = `0x000F00xx` (CONFIG RX + RF_SETUP + CH)
- `0x2000000C` = `0` → **no packets / no RPD** (RF not arriving)

1. **VCC = 3.3 V** on *both* sides. Nucleo/Pi **5 V on VCC** destroys PA/LNA (SPI still OK).
2. **Separate modules ~0.5–1 m** (PA+LNA at 5 cm can saturate even at PA_MIN).
3. Antennas screwed on (you already have this).
4. Optional: 10–100 µF across adapter VCC–GND.
## Nucleo ↔ Nucleo (no Pi / no UART)

| Role | ELF | LED at boot |
|---|-----|---|
| RX peer | `test_nrf_link_rx.elf` | 3 short blinks; blink on each PING |
| TX client | `test_nrf_link_tx.elf` | 2 long blinks; solid LED = all PONGs OK |

Flash RX first (leave that board powered), then flash TX on the other:

```bash
openocd -f interface/stlink.cfg -f target/stm32l4x.cfg \
  -c "init" -c "program test_nrf_link_rx.elf verify reset exit"
# swap USB to the other Nucleo (or use a 2nd cable)
openocd -f interface/stlink.cfg -f target/stm32l4x.cfg \
  -c "init" -c "program test_nrf_link_tx.elf verify reset exit"
# read TX result
openocd -f interface/stlink.cfg -f target/stm32l4x.cfg \
  -c "init" -c "halt" -c "mdw 0x20000000 4" -c "resume" -c "shutdown"
```

TX magic: `0xA55A00FF` PASS, `0xA55A00FE` partial, `0xA55A00F0` fail.  
CE on **D3** for both (not hard-tied to 3.3V). **VCC = 3.3 V**.

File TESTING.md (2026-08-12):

# WiFeeder v2 — Testing Plan

---

## 1. Test Pyramid

```mermaid
graph TB
    subgraph System[" System Tests (Manual)"]
        S1["Full day feeding simulation"]
        S2["Multi-actuator stress test"]
        S3["Power failure recovery"]
        S4["Range interference test"]
    end

    subgraph Integration[" Integration Tests (Semi-Automated)"]
        I1["NRF TX/RX loopback"]
        I2["RFID → FEED_CMD cycle"]
        I3["Motor encoder accuracy"]
        I4["HX711 calibration"]
        I5["Database CRUD"]
        I6["MQTT publish/subscribe"]
    end

    subgraph Unit[" Unit Tests (Automated)"]
        U1["CRC-8 calculation"]
        U2["Message pack/unpack"]
        U3["RFID frame parser"]
        U4["Diet calculator"]
        U5["NRF SPI driver"]
        U6["PWM generation"]
    end

    System --> Integration
    Integration --> Unit
```

---

## 2. Unit Tests

### 2.1 CRC-8 Tests

| Test ID | Description | Input | Expected |
|---|---|---|---|
| CRC-001 | Empty buffer | `""` | `0x00` |
| CRC-002 | Known vector | `"123456789"` | `0xF4` |
| CRC-003 | Single byte | `"\x00"` | `0x00` |
| CRC-004 | Single byte | `"\xFF"` | `0xF7` |
| CRC-005 | All message types | All msg types | Consistent |

### 2.2 Message Pack/Unpack Tests

| Test ID | Description | Action | Expected |
|---|---|---|---|
| MSG-001 | Pack STATUS | Serialize struct | Correct bytes |
| MSG-002 | Pack RFID_TAG | Serialize struct | Correct bytes |
| MSG-003 | Pack FEED_CMD | Serialize struct | Correct bytes |
| MSG-004 | Unpack STATUS | Deserialize bytes | Correct struct |
| MSG-005 | Unpack corrupted | Invalid CRC | Return error |
| MSG-006 | Unpack wrong size | Size < 4 | Return error |

### 2.3 RFID Frame Parser

| Test ID | Description | Input | Expected |
|---|---|---|---|
| RFID-001 | Valid frame | `"$A0112OKD199462190123456AB"` | `tag_id=19946219` |
| RFID-002 | Bad header | `"$X0112OKD199462190123456AB"` | `Failure_BadFormat` |
| RFID-003 | Bad checksum | `"$A0112OKD19946219012345600"` | `Failure_BadFormat` |
| RFID-004 | Short frame | `"$A0112OKD123"` | `Failure_BadFormat` |
| RFID-005 | Empty frame | `""` | `Failure_BadFormat` |

### 2.4 Diet Calculator

| Test ID | Description | Input | Expected |
|---|---|---|---|
| DIET-001 | First feed of day | `dayweight=0, dayleft=3000` | `portion=p_max` |
| DIET-002 | Mid-day feed | `dayweight=1500, dayleft=1500` | `portion=375` |
| DIET-003 | Last portion | `dayleft < p_max` | `portion=dayleft` |
| DIET-004 | Daily limit hit | `dayweight >= d_max` | `portion=0` |
| DIET-005 | Outside feeding window | `time < start` | `portion=0` |
| DIET-006 | Interval too short | `time_since_last < inter` | `portion=0` |

---

## 3. Integration Tests

### 3.1 NRF Communication Test

```mermaid
sequenceDiagram
    participant STM32 as STM32
    participant RPi as RPi

    Note over STM32,RPi: Test 1: Basic TX/RX
    STM32->>RPi: STATUS (heartbeat=1)
    RPi->>RPi: Validate CRC
    RPi->>STM32: ACK
    STM32->>STM32: Verify ACK received

    Note over STM32,RPi: Test 2: Large payload
    STM32->>RPi: STATUS (with max data)
    RPi->>RPi: Validate all bytes
    RPi->>STM32: ACK

    Note over STM32,RPi: Test 3: 1000 packets
    loop 1000 times
        STM32->>RPi: STATUS (heartbeat=N)
        RPi->>STM32: ACK
    end
    Note over STM32,RPi: Verify: < 1% packet loss
```

### 3.2 RFID → Feed Cycle Test

| Step | Action | Expected |
|---|---|---|
| 1 | Present known RFID tag | Tag ID read correctly |
| 2 | STM32 sends RFID_TAG | RPi receives |
| 3 | RPi calculates portion | Correct motor revs |
| 4 | RPi sends FEED_CMD | STM32 receives |
| 5 | Motors activate | Both motors spin |
| 6 | Encoders count | Correct revs dispensed |
| 7 | STM32 sends FEED_DONE | RPi receives |
| 8 | Database updated | Consumption recorded |

### 3.3 Motor & Encoder Accuracy

| Test ID | Target Revs | Tolerance | Pass Criteria |
|---|---|---|---|
| MTR-001 | 1 rev | ±10% | 360-440 encoder counts |
| MTR-002 | 5 revs | ±10% | 1800-2200 encoder counts |
| MTR-003 | 10 revs | ±5% | 3800-4200 encoder counts |
| MTR-004 | 50 revs | ±5% | 19000-21000 encoder counts |
| MTR-005 | Start/stop rapid | No stall | Motor completes cycle |

---

## 4. System Tests

### 4.1 End-to-End Feeding Test

```mermaid
sequenceDiagram
    participant Cow as  Test Cow
    participant Feeder as Feeder System
    participant Cloud as Agpro Cloud

    loop 10 times
        Cow->>Feeder: RFID tag detected
        Feeder->>Feeder: Calculate portion
        Feeder->>Feeder: Dispense feed
        Feeder->>Cloud: Report consumption
        Note over Cow: Wait 30s (inter-feed timeout)
    end

    Note over Cow,Cloud: Verify:
    Note over Cow,Cloud: 1. All 10 feeds successful
    Note over Cow,Cloud: 2. Portion accuracy ±5%
    Note over Cow,Cloud: 3. All MQTT events received
    Note over Cow,Cloud: 4. No packet loss > 1%
```

### 4.2 Multi-Actuator Test

| Test | Actuators | Duration | Success Criteria |
|---|---|---|---|
| 3 simultaneous feeds | 3 | 10 min | All complete, no collisions |
| Alternating feeds | 5 | 30 min | No cross-talk, all feed correctly |
| Max load | 6 | 1 hour | System stable, all ACKnowledged |

### 4.3 Range Test

| Distance | Environment | Expected Packet Loss |
|---|---|---|
| 5m | Indoor (open) | < 0.1% |
| 15m | Indoor (walls) | < 1% |
| 30m | Indoor (walls) | < 5% |
| 50m | Outdoor (LOS) | < 2% |
| 100m | Outdoor (LOS) | < 5% |

### 4.4 Recovery Tests

| Test | Scenario | Expected |
|---|---|---|
| RPi reboot | Power cycle Pi mid-feed | STM32 detects disconnect, retries; recovers when Pi comes back |
| STM32 reboot | Power cycle STM32 mid-feed | STM32 boots clean; Pi detects reconnect |
| NRF interference | Wi-Fi channel congestion | Auto-ack handles retries; rate < 1% loss |
| Battery low | Voltage drops to 10V | STM32 sends BATTERY_LOW; Pi logs alert |
| Motor stall | Block motor mechanically | STM32 detects stall; sends ERROR; Pi alerts |

---

## 5. Performance Benchmarks

| Metric | Target | Measurement Method |
|---|---|---|
| NRF TX success rate | > 99% | Count ACKed vs sent packets over 1h |
| Packet latency (TX→ACK) | < 5 ms | Oscilloscope on CE/IRQ pins |
| RFID read latency | < 100 ms | From tag detection to packet sent |
| Feed command latency | < 200 ms | From RPi decision to motor start |
| Motor control accuracy | ±5% | Encoder count vs target |
| CPU usage (STM32) | < 50% | FreeRTOS task statistics |
| CPU usage (RPi) | < 20% | `top` / `htop` monitoring |
| RAM usage (STM32) | < 40 KB | Linker map analysis |
| Battery life (idle) | > 24 hours | 12V 7Ah battery |

---

## 6. Test Environment Setup

### 6.1 STM32 Test Setup

```bash
# Unit tests (Unity framework)
cd stm32/tests
mkdir build && cd build
cmake ..
cmake --build .
ctest --output-on-failure

# NRF loopback test
# Connect NRF24L01+ module to STM32
# Use second NRF connected to PC via Arduino/FTDI
```

### 6.2 Raspberry Pi Test Setup

```bash
# Unit tests (Google Test)
cd raspberry/tests
mkdir build && cd build
cmake ..
cmake --build .
ctest --output-on-failure

# NRF test (with second NRF on Pi)
sudo ./test_nrf_txrx
```

### 6.3 Virtual NRF Test (No Hardware)

```bash
# Use socat to create virtual SPI devices
socat PTY,link=/tmp/nrf_stm PTY,link=/tmp/nrf_pi

# Run test with virtual devices
python3 tests/virtual_nrf_test.py
```

---

## 7. Acceptance Criteria

```mermaid
graph TD
    START["Start Acceptance Test"] --> A1["100 feed cycles<br/>without errors"]
    A1 --> A2["< 1% packet loss<br/>over 1 hour"]
    A2 --> A3["±5% feed accuracy<br/>for all animals"]
    A3 --> A4["MQTT events<br/>all received by cloud"]
    A4 --> A5["24h battery life<br/>with 2 feeds/h"]
    A5 --> A6["Automatic recovery<br/>from power loss"]
    A6 --> PASS[" ACCEPTED"]

    A1 --> FAIL[" REJECTED"]
    A2 --> FAIL
    A3 --> FAIL
    A4 --> FAIL
    A5 --> FAIL
    A6 --> FAIL
```

### Checklist

- [ ] 100 consecutive successful feed cycles
- [ ] < 1% communication failure rate
- [ ] ±5% feed quantity accuracy
- [ ] All MQTT events received by cloud
- [ ] 24-hour continuous operation without manual intervention
- [ ] Automatic recovery from power off/on
- [ ] Automatic recovery from NRF disconnection
- [ ] Motor stall detection works
- [ ] RFID error handling works
- [ ] Database integrity maintained

---

## 8. Regression Test Suite

After each firmware/software update, run:

```bash
#!/bin/bash
# scripts/run_all_tests.sh

echo "=== Unit Tests ==="
cd stm32/tests/build && ctest
cd raspberry/tests/build && ctest

echo "=== Integration Tests ==="
python3 tests/integration/test_nrf_comm.py
python3 tests/integration/test_feed_cycle.py

echo "=== System Tests ==="
# Requires hardware setup
python3 tests/system/test_full_cycle.py --cycles 10
python3 tests/system/test_multi_actuator.py --actuators 3
```

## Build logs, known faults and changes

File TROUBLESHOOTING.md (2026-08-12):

# WiFeeder v2 — Troubleshooting Guide

---

## Table of Contents

1. [NRF24L01+ Communication Issues](#nrf24l01-communication-issues)
2. [RFID Reader Issues](#rfid-reader-issues)
3. [Motor Control Issues](#motor-control-issues)
4. [Power Issues](#power-issues)
5. [Database Issues](#database-issues)
6. [MQTT Issues](#mqtt-issues)
7. [Diagnostic Commands](#diagnostic-commands)

---

## 1. NRF24L01+ Communication Issues

### 1.1 No Communication at All

```mermaid
flowchart TD
    START["NRF not communicating"] --> A{"SPI device present?"}
    A -->|"Yes"| B{"Wiring correct?"}
    A -->|"No"| FIX1["Enable SPI in raspi-config<br/>Check /dev/spidev0.0"]
    B -->|"Yes"| C{"Power 3.3V?"}
    B -->|"No"| FIX2["Check wiring:<br/>MOSI, MISO, SCK, CSN, CE"]
    C -->|"Yes"| D{"NRF responds<br/>to SPI?"}
    C -->|"No"| FIX3["3.3V rail may be overloaded.<br/>Check power supply."]
    D -->|"Yes"| E{"Same channel<br/>on both?"}
    D -->|"No"| FIX4["NRF module may be damaged.<br/>Replace."]
    E -->|"Yes"| F{"Same address<br/>on both?"}
    E -->|"No"| FIX5["Set RF_CH=76 on both sides"]
    F -->|"Yes"| G{"Auto-ACK working?"}
    F -->|"No"| FIX6["Set TX_ADDR on STM32 =<br/>RX_ADDR_P0 on RPi"]
    G -->|"Yes"| OK[" Communication OK"]
    G -->|"No"| FIX7["Enable EN_AA, check<br/>SETUP_RETR settings"]
```

### 1.2 Common NRF Errors

| Symptom | Likely Cause | Fix |
|---|---|-----|
| MAX_RT (max retries) | No receiver listening | Check RPi NRF is in RX mode |
| No IRQ after TX | IRQ pin not connected | Check PB1 (STM32) or GPIO24 (RPi) |
| Intermittent packets | Interference | Change NRF channel (avoid Wi-Fi channels) |
| Short range | Antenna damaged | Replace NRF module; use PA+LNA version |
| SPI read returns 0x00 | NRF not powered | Check 3.3V power; check module orientation |

### 1.3 NRF Diagnostic Commands

```bash
# On Raspberry Pi:
cd /opt/wifeeder-v2/raspberry
sudo ./nrf_test --diagnostic

# Expected output:
# STATUS = 0x0E (RX mode, no pending interrupts)
# FIFO_STATUS = 0x11 (TX empty, RX empty)
# RF_CH = 76
# RF_SETUP = 0x06 (1Mbps, 0dBm)
# CONFIG = 0x0F (RX mode, CRC 2-byte, power up)
```

---

## 2. RFID Reader Issues

### 2.1 RFID Not Reading Tags

```mermaid
flowchart TD
    START["RFID not reading"] --> A{"Reader powered?"}
    A -->|"Yes"| B{"Receiving data<br/>on UART2?"}
    A -->|"No"| F1["Check 5V/3.3V power<br/>to RFID reader"]
    B -->|"Yes"| C{"Frame format<br/>correct?"}
    B -->|"No"| F2["Check UART2 wiring:<br/>PA3 (RX) ↔ RFID TX<br/>PA2 (TX) ↔ RFID RX<br/>9600 baud, 8N1"]
    C -->|"Yes"| D{"Tag ID valid?"}
    C -->|"No"| F3["Frame must start with<br/>$A0112OKD, 27 bytes"]
    D -->|"Yes"| OK[" RFID working"]
    D -->|"No"| F4["Check tag format:<br/>EM4100 26-bit<br/>Verify with test tag"]
```

### 2.2 RFID Error Codes

| Error | Meaning | Fix |
|---|---|-----|
| `Failure_EmptyFifo` | No data from reader | Check reader power and UART wiring |
| `Failure_BadFormat` | Frame header mismatch | Reader may be different model; check format |
| `Failure_BadFormat` + checksum | Checksum error | Noise on UART line; check grounding |

### 2.3 RFID Test Command

```c
// In STM32 CLI:
rfid-test          // Scan for RFID activity
rfid-status        // Show reader health

// Expected output:
// RFID Reader: ONLINE
// Last Tag: 19946219
// Reads today: 15
// Errors today: 0
```

---

## 3. Motor Control Issues

### 3.1 Motor Not Spinning

```mermaid
flowchart TD
    START["Motor not spinning"] --> A{"IBT-2 powered?"}
    A -->|"Yes"| B{"Enable tied to 3.3V?"}
    A -->|"No"| F1["Check 12V to IBT-2 VCC<br/>Motor wires to M+/M-"]
    B -->|"Yes"| C{"PWM signal present?"}
    B -->|"No"| F2["Tie R_EN and L_EN to 3.3V"]
    C -->|"Yes"| D{"Direction set?"}
    C -->|"No"| F3["Check TIM1_CH1 PA8 or TIM16_CH1 PB6<br/>PWM at 10 kHz"]
    D -->|"Yes"| E{"Motor OK?"}
    D -->|"No"| F4["Set LPWM LOW for forward<br/>RPWM LOW, LPWM PWM for reverse"]
    E -->|"Yes"| OK["Motor spinning"]
    E -->|"No"| F5["Motor may be damaged<br/>Check with 12V directly"]
```

### 3.2 Encoder Not Counting

| Symptom | Likely Cause | Fix |
|---|---|-----|
| Encoder count stays 0 | Encoder not powered | Check 5V from IBT-2 to encoder VCC |
| Encoder count erratic | Noise on encoder lines | Add 100nF capacitor between A/B and GND |
| Encoder count wrong direction | Wires swapped | Swap A and B wires, or swap TIM config |
| Encoder only counts one direction | Missing B signal | Check B wire connection |

### 3.3 Motor Control Diagnostics

```c
// STM32 CLI:
m 1 1             // Test motor 1: 1 revolution
m 2 1             // Test motor 2: 1 revolution
encoder-status    // Show encoder counts

// Expected output for m 1 1:
// Start Motor 1 for 1 Revolutions
// Encoder count: 400 (or ~1600 in 4x mode)
// Motor 1 Status: 0 (OK)
```

---

## 4. Power Issues

### 4.1 Mini360 DC-DC Converter

| Symptom | Likely Cause | Fix |
|---|---|-----|
| No output | Input polarity reversed | Check 12V + / - connections |
| Output voltage low | Load too high | Reduce load or use higher-rated converter |
| Output unstable | Input too low | Battery voltage > 5V minimum |
| Converter hot | Over-current | Add heatsink; use separate converter for high loads |

### 4.2 Power Diagnostics

```bash
# Measure voltages:
# Mini360 input:  12V (from battery)
# Mini360 output:  3.3V ±0.1V (multimeter)
# NRF VCC:         3.3V
# STM32 3.3V pin:  3.3V
# RFID VCC:        3.3V or 5V (depending on model)
# IBT-2 VCC:       12V
# Motor terminals: 0-12V (varies with PWM duty)
```

---

## 5. Database Issues

### 5.1 SQLite Errors

| Error | Meaning | Fix |
|---|---|-----|
| `unable to open database` | File not found or permissions | Check path `/etc/wifeeder-v2/wifeeder.db` |
| `database is locked` | Concurrent write access | Check mutex usage; don't open DB in multiple threads |
| `no such table` | Schema not applied | Run `schema.sql` |
| `disk I/O error` | SD card full or failing | Free space: `df -h /`; check SD health |

### 5.2 Database Repair

```bash
# Check database integrity
sqlite3 /etc/wifeeder-v2/wifeeder.db "PRAGMA integrity_check;"

# Backup database
cp /etc/wifeeder-v2/wifeeder.db /etc/wifeeder-v2/wifeeder.db.backup

# Rebuild corrupted database
sqlite3 /etc/wifeeder-v2/wifeeder.db ".recover" | sqlite3 /etc/wifeeder-v2/wifeeder_new.db
mv /etc/wifeeder-v2/wifeeder_new.db /etc/wifeeder-v2/wifeeder.db
```

---

## 6. MQTT Issues

### 6.1 MQTT Connection Problems

| Symptom | Likely Cause | Fix |
|---|---|-----|
| `Connection refused` | Mosquitto not running | `sudo systemctl start mosquitto` |
| `Bad username or password` | Wrong credentials | Check `/etc/mosquitto/passwd` |
| `Connection timeout` | Firewall blocking 1883 | `sudo ufw allow 1883` |
| Messages not reaching cloud | Internet down | Check `ping agpro-server.com` |

### 6.2 MQTT Diagnostics

```bash
# Check Mosquitto status
sudo systemctl status mosquitto

# Check MQTT logs
sudo tail -f /var/log/mosquitto/mosquitto.log

# Test publish
mosquitto_pub -h localhost -u client2 -P 'wifeeder@agTEK.2020_2_mqtt' \
    -t 'WCN-A100-0001X/test' -m 'hello'

# Test subscribe (in another terminal)
mosquitto_sub -h localhost -u client2 -P 'wifeeder@agTEK.2020_2_mqtt' \
    -t 'WCN-A100-0001X/#' -v
```

---

## 7. Diagnostic Commands

### 7.1 STM32 CLI Commands

| Command | Description |
|---|---|
| `help` | Show all commands |
| `get-id` | Show device ID |
| `get-type` | Show machine type |
| `nrf-status` | Show NRF24L01+ status |
| `nrf-stats` | Show NRF statistics (sent/rcvd/errors) |
| `nrf-channel <ch>` | Set NRF channel |
| `rfid-status` | Show RFID reader status |
| `rfid-test` | Test RFID reader (scan GPIOs) |
| `m <1/2> <revs>` | Test motor for N revolutions |
| `encoder-status` | Show encoder counts |
| `hx711-test` | Read HX711 raw value |
| `reset` | Software reset MCU |

### 7.2 Raspberry Pi Diagnostic Commands

```bash
# Check service
systemctl status wifeeder-v2

# View logs
journalctl -u wifeeder-v2 -f -n 100

# Check NRF
sudo /opt/wifeeder-v2/raspberry/nrf_test --diagnostic

# Check database
sqlite3 /etc/wifeeder-v2/wifeeder.db "SELECT COUNT(*) FROM feed_history;"

# Check MQTT
mosquitto_sub -h localhost -u client2 -P 'wifeeder@agTEK.2020_2_mqtt' \
    -t 'WCN-A100-0001X/#' -C 1 -W 5
```

---

## 8. Emergency Recovery

### 8.1 STM32 Not Responding

```bash
# 1. Connect ST-Link to NUCLEO
# 2. Force mass erase and reflash
openocd -f interface/stlink.cfg -f target/stm32l4x.cfg \
    -c "init" -c "halt" \
    -c "stm32l4x mass_erase 0" \
    -c "program wifeeder_mcu.bin 0x08000000 verify reset exit"
```

### 8.2 RPi Not Booting

```bash
# 1. Insert fresh SD card with Raspbian
# 2. Run setup script
sudo bash /opt/wifeeder-v2/scripts/setup_pi.sh
# 3. Restore database backup
sudo cp /backup/wifeeder.db /etc/wifeeder-v2/
```

### 8.3 Complete NRF Failure

If both NRF modules are damaged and communication is impossible:

```bash
# Fallback to UART communication (emergency mode)
# On STM32: connect debug UART (PA9/PA10) to RPi UART (GPIO14/15)
# On RPi: enable UART and run emergency protocol
sudo /opt/wifeeder-v2/raspberry/wifeeder_host --emergency-mode --serial /dev/ttyS0
```

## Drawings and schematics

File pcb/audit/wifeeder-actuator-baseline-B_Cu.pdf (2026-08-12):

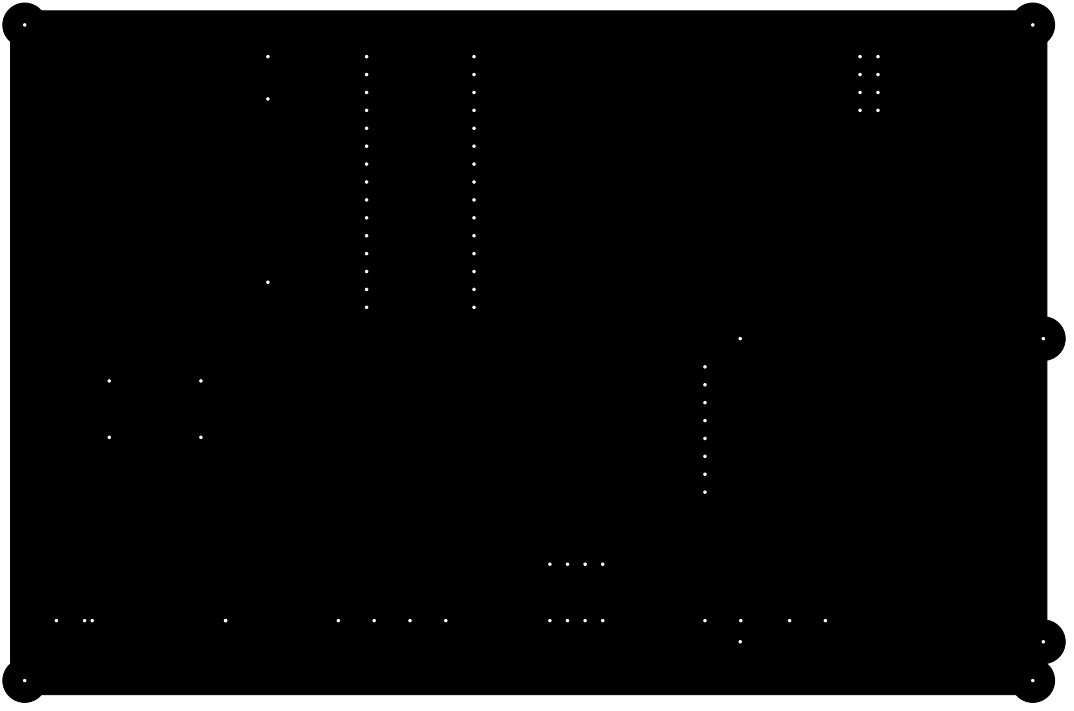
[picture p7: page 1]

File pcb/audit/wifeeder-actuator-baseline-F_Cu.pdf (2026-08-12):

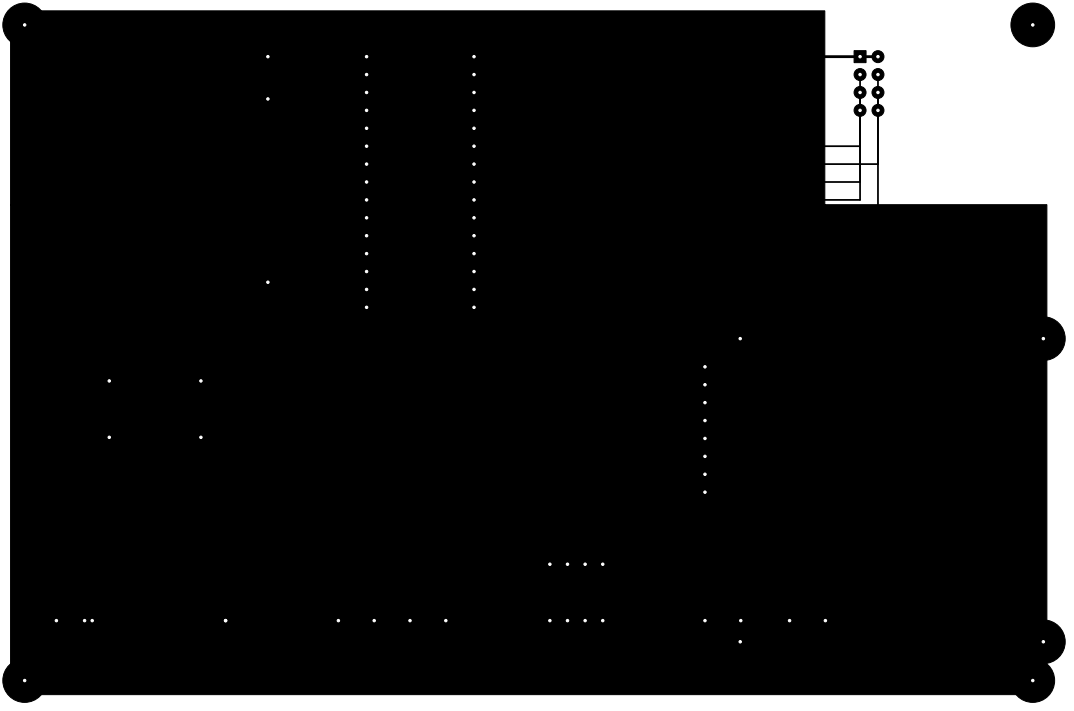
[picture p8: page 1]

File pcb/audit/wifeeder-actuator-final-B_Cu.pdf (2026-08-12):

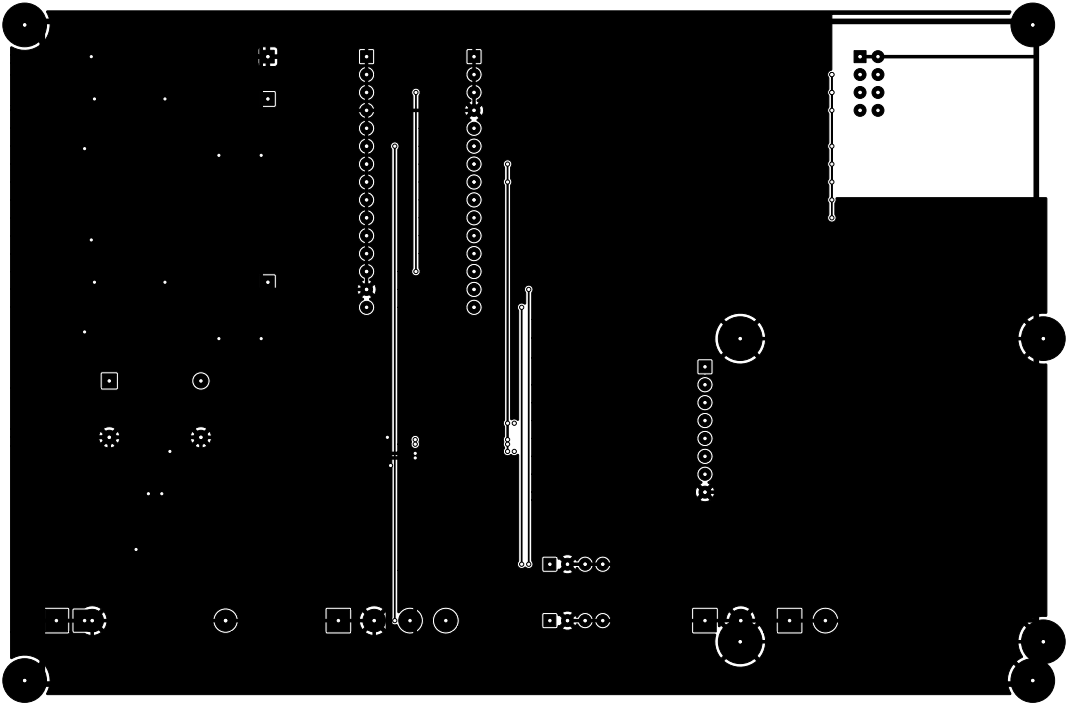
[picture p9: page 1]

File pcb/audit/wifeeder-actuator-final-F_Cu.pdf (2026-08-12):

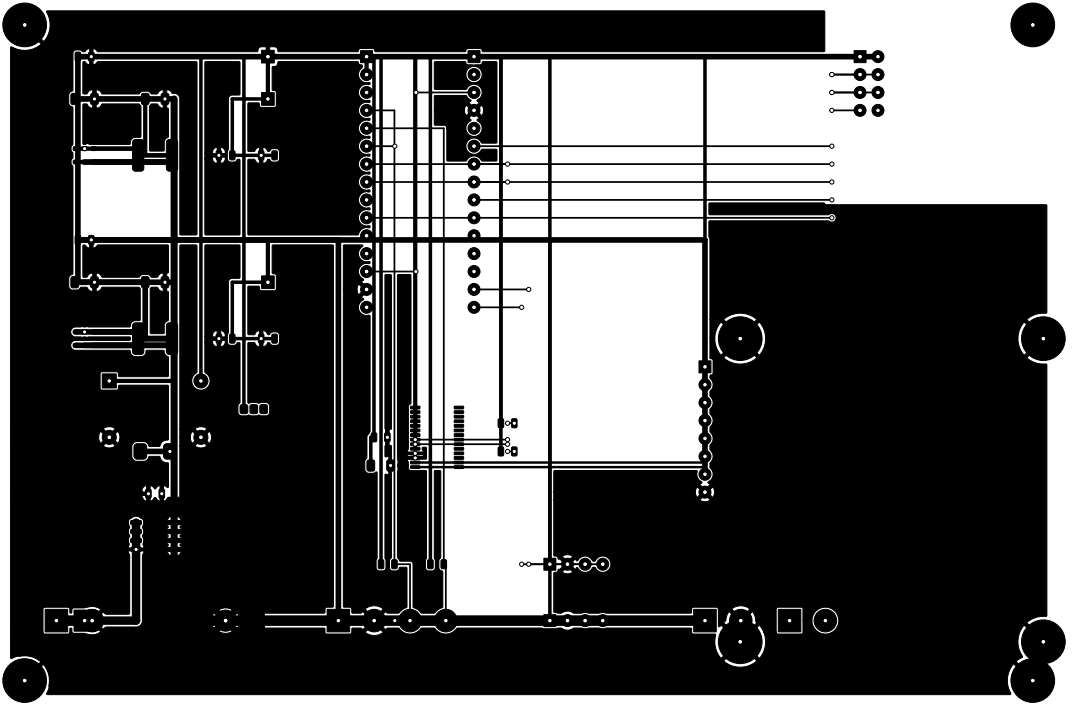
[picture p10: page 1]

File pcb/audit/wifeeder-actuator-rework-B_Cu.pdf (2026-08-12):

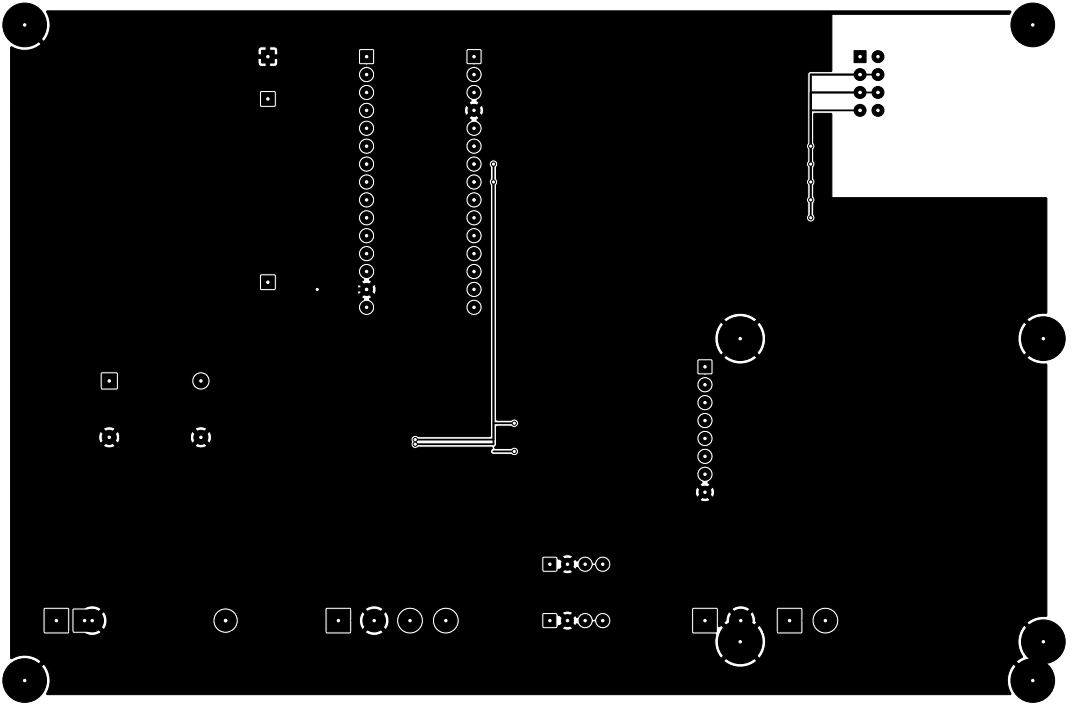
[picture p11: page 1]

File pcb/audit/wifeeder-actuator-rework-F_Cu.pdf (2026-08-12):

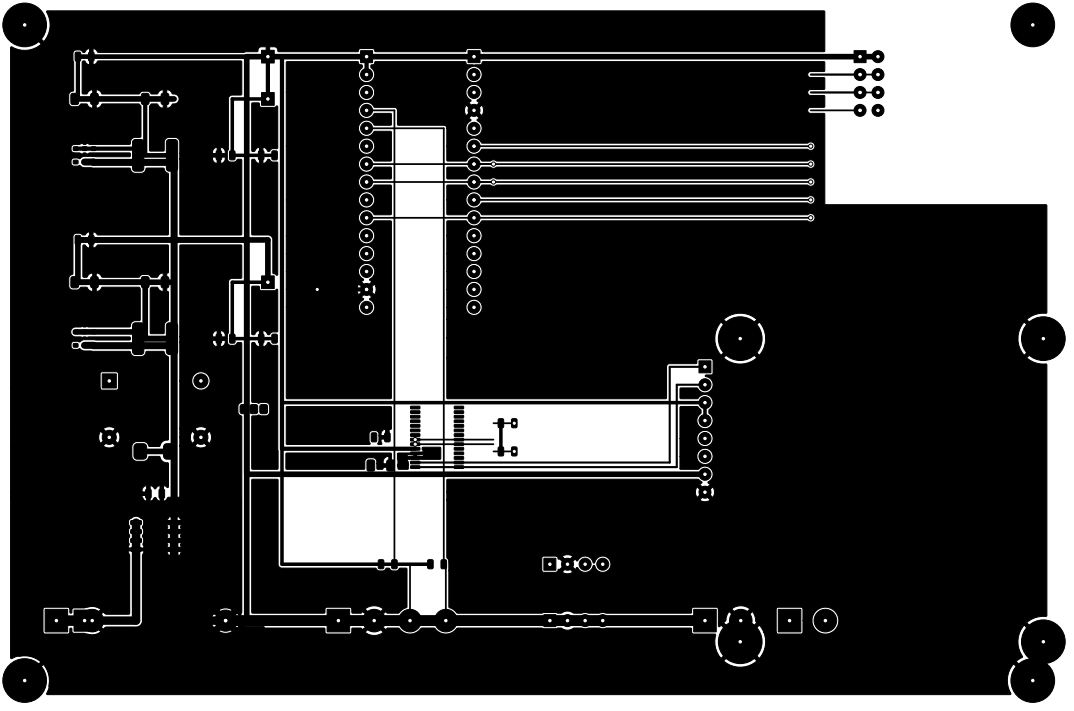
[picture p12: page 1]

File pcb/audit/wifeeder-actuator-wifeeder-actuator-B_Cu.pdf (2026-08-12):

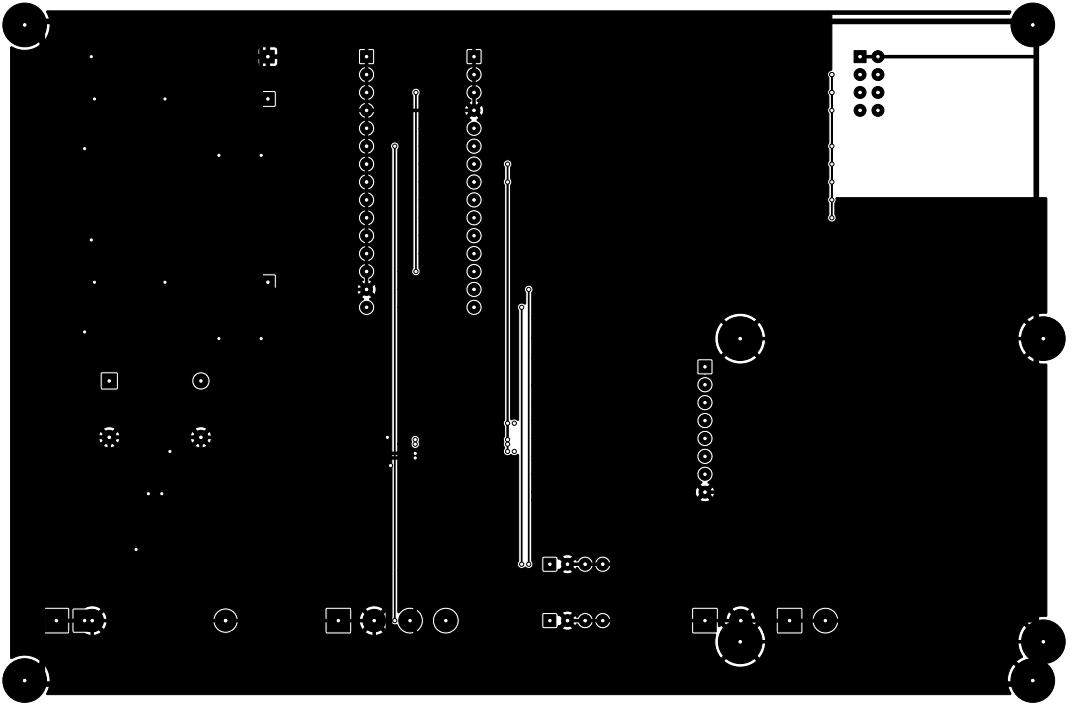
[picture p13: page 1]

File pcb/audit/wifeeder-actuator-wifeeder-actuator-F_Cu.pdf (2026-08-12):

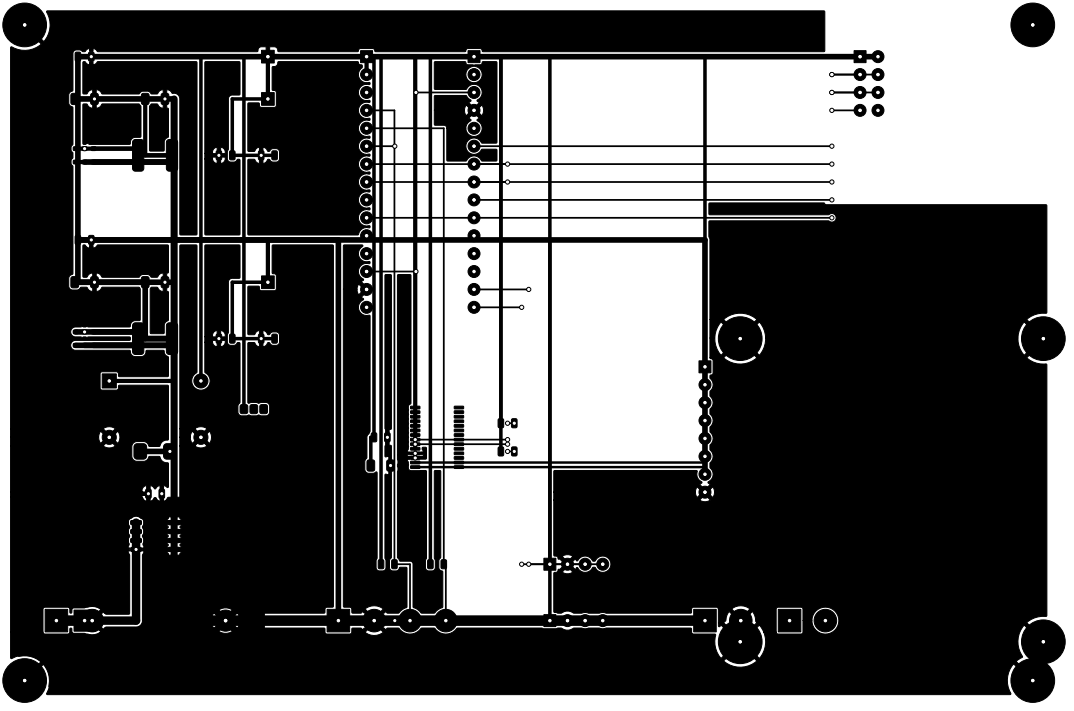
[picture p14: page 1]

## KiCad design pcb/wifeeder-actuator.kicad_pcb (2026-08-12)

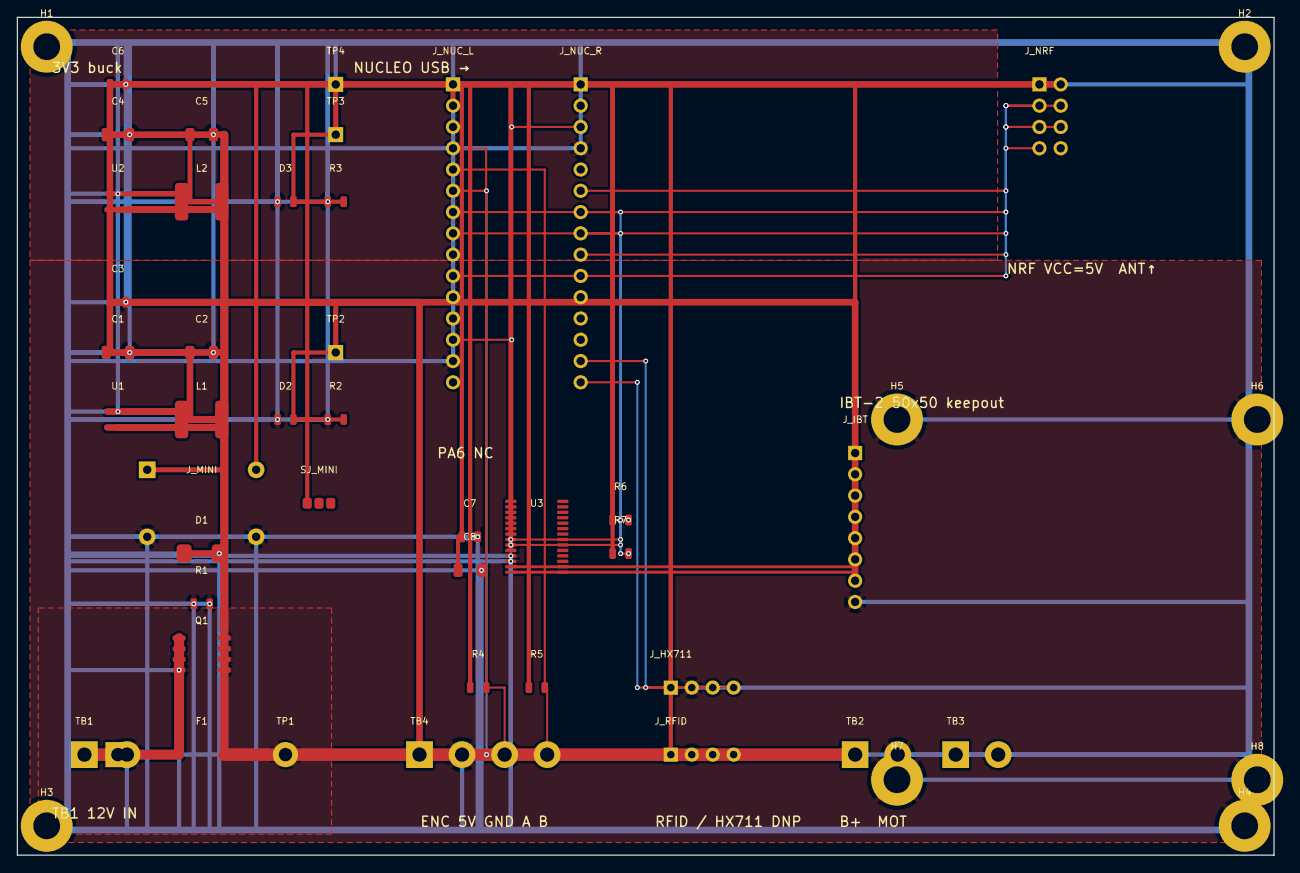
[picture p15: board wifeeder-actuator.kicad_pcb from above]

Board: 2 copper layers, 150.0 x 100.0 mm, 49 parts (0 on the bottom side), 20 nets.

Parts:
C1, C4, C8: 10uF; C_1206
C2, C5: 22uF; C_1206
C3, C6, C7: 100n; C_0805
D1: SMAJ15A; SMA
D2: 5V; LED_0805
D3: 3V3; LED_0805
F1: 10A; Fuse_5x20
H1, H2, H3, H4: M3; MountingHole_M3
H5, H6, H7, H8: IBT; MountingHole_M3
J_HX711: HX711; JST_XH_04
J_IBT: IBT logic; PinSocket_1x08
J_MINI: DNP; Mini360
J_NRF: NRF 5V; PinSocket_2x04
J_NUC_L: CN3; PinSocket_1x15
J_NUC_R: CN4; PinSocket_1x15
J_RFID: RFID; JST_XH_04
L1, L2: 4.7uH; L_6x6
Q1: AO4407A; SOIC-8
R1: 100k; R_0805
R2, R3: 1k; R_0805
R4, R5, R6, R7: 4.7k; R_0805
SJ_MINI: OPEN; SolderJumper_3
TB1: 12V_IN; Terminal_2
TB2: IBT B+; Terminal_2
TB3: MOTOR; Terminal_2
TB4: ENC; Terminal_4
TP1: 12V; TestPoint
TP2: 5V; TestPoint
TP3: 3V3; TestPoint
TP4: GND; TestPoint
U1: AP63205; SOT23-6
U2: AP63203; SOT23-6
U3: PCA9685; TSSOP-28

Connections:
3V3: C5.1, C6.1, C7.1, C8.1, D3.2, J_HX711.1, J_IBT.3, J_IBT.4, J_MINI.3, J_NUC_L.2, L2.1, L2.2, R3.2, R4.1, R5.1, R6.1, R7.1, SJ_MINI.1, TP3.1, U2.1, U2.3, U2.6, U3.10
5V: C2.1, C3.1, D2.2, J_IBT.7, J_NRF.2, J_RFID.1, L1.1, L1.2, R2.2, TB4.1, TP2.1, U1.1, U1.3, U1.6
12V_IN: F1.1, Q1.1, Q1.2, Q1.3, TB1.1
12V_SAFE: C1.1, C4.1, D1.1, F1.2, J_MINI.1, Q1.5, Q1.6, Q1.7, Q1.8, TB2.1, TP1.1, U1.4, U1.5, U2.4, U2.5
ENC_A: J_NUC_L.4, R4.2, TB4.3
ENC_B: J_NUC_L.5, R5.2, TB4.4
GND: C1.2, C2.2, C3.2, C4.2, C5.2, C6.2, C7.2, C8.2, D1.2, D2.1, D3.1, J_HX711.2, J_IBT.8, J_MINI.2, J_MINI.4, J_NRF.1, J_NUC_L.14, J_NUC_R.4, J_RFID.2, Q1.4, R1.1, R1.2, R2.1, R3.1, TB1.2, TB2.2, TB4.2, TP4.1, U1.2, U2.2, U3.11, U3.12
HX711_DOUT: J_HX711.3, J_NUC_R.15
HX711_SCK: J_HX711.4, J_NUC_R.14
I2C_SCL: J_NUC_R.8, R6.2, U3.8
I2C_SDA: J_NUC_R.7, R7.2, U3.9
NRF_CE: J_NRF.3, J_NUC_R.6
NRF_CSN: J_NRF.4, J_NUC_L.7
NRF_MISO: J_NRF.7, J_NUC_R.9
NRF_MOSI: J_NRF.6, J_NUC_L.10
NRF_SCK: J_NRF.5, J_NUC_L.8
NUC_NRST: J_NUC_L.13, J_NUC_R.3
PWM0: J_IBT.1, U3.13
PWM1: J_IBT.2, U3.14
RFID_RX: J_NUC_L.6, J_RFID.3

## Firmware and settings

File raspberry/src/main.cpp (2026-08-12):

#include "config.h"
#include "database.h"
#include "diet_engine.h"
#include "mqtt_client.h"
#include "nrf_link.h"
#include "protocol.h"

#include <atomic>
#include <chrono>
#include <csignal>
#include <cstring>
#include <iostream>
#include <map>
#include <mutex>
#include <thread>

using namespace wifeeder;

static std::atomic<bool> g_stop{false};
static NrfLink g_link;
static Database* g_db = nullptr;
static MqttClient* g_mqtt = nullptr;

static std::mutex g_wa_mtx;
static std::map<uint8_t, std::time_t> g_wa_last_rx;
static std::map<uint8_t, int32_t> g_wa_conn_status;

static std::mutex g_daily_mtx;

static void handle_signal(int)
{
    g_stop = true;
}

static std::string data_path()
{
    const char* env = std::getenv("WIFEEDER_DATA");
    return env != nullptr ? std::string(env) : DEFAULT_DATA_PATH;
}

static void send_ack(uint8_t dest, uint8_t echo_type)
{
    ProtoAck ack{};
    ack.echo_msg_type = echo_type;
    ack.status = PROTO_ACK_OK;
    g_link.sendto(PROTO_MSG_ACK, dest, &ack, sizeof(ack));
}

static bool packet_from_message(const NrfMessage& msg, ProtoPacket& pkt)
{
    std::vector<uint8_t> raw(PROTO_HEADER_SIZE + msg.payload.size() + 1U);
    raw[0] = msg.dest_id;
    raw[1] = msg.src_id;
    raw[2] = msg.msg_type;
    raw[3] = msg.seq;
    if (!msg.payload.empty()) {
        std::memcpy(raw.data() + 4, msg.payload.data(), msg.payload.size());
    }
    raw.back() = crc8_calc(raw.data(), raw.size() - 1U);
    return Protocol::unpack(raw.data(), raw.size(), pkt);
}

static int32_t handle_rfid_tag(uint8_t src_id, const ProtoRfidTag& tag)
{
    if (!rfid_is_valid(tag.tag_id)) {
        std::cerr << "[feed] invalid RFID " << tag.tag_id << std::endl;
        return ENOERR;
    }

    std::vector<uint32_t> p_qty;
    ProtoFeedCmd cmd{};
    cmd.animal_id = tag.tag_id;

    try {
        JsonValue json_anim = g_db->get_animal_json(tag.tag_id);
        DietEngine diet(json_anim["diet"]);
        diet.get_portion(p_qty);

        if (!p_qty.empty() && p_qty[0] >= DEF_CALIBER_REF_REVS) {
            const uint32_t density = diet.target_json()["target"][static_cast<size_t>(0)]
                .get("density", JsonValue(static_cast<unsigned int>(480))).asUInt();
            cmd.motor1_revs = static_cast<uint16_t>(grams_to_revs(p_qty[0], density));
        }
        if (p_qty.size() > 1 && p_qty[1] >= DEF_CALIBER_REF_REVS) {
            const uint32_t density = diet.target_json()["target"][static_cast<size_t>(1)]
                .get("density", JsonValue(static_cast<unsigned int>(480))).asUInt();
            cmd.motor2_revs = static_cast<uint16_t>(grams_to_revs(p_qty[1], density));
        }
    } catch (const std::exception& ex) {
        std::cerr << "[feed] RFID lookup failed for " << tag.tag_id << ": " << ex.what() << std::endl;
        JsonValue uplink;
        uplink["unknown_rfid"] = static_cast<unsigned int>(tag.tag_id);
        g_mqtt->publish(MQTT_TOPIC_DIET_UASYNC, uplink.dump());
    }

    std::cout << "[feed] FEED_CMD animal=" << cmd.animal_id
              << " m1=" << cmd.motor1_revs << " m2=" << cmd.motor2_revs << std::endl;
    return g_link.sendto(PROTO_MSG_FEED_CMD, src_id, &cmd, sizeof(cmd));
}

static void handle_feed_done(uint8_t src_id, const ProtoFeedDone& done)
{
    (void)src_id;
    std::vector<uint32_t> p_eff;
    try {
        JsonValue json_anim = g_db->get_animal_json(done.animal_id);
        DietEngine diet(json_anim["diet"]);
        const uint32_t density0 = diet.target_json()["target"][static_cast<size_t>(0)]
            .get("density", JsonValue(static_cast<unsigned int>(480))).asUInt();
        p_eff.push_back(revs_to_grams(done.motor1_actual, density0));
        if (diet.target_json()["target"].size() > 1) {
            const uint32_t density1 = diet.target_json()["target"][static_cast<size_t>(1)]
                .get("density", JsonValue(static_cast<unsigned int>(480))).asUInt();
            p_eff.push_back(revs_to_grams(done.motor2_actual, density1));
        }

        std::lock_guard<std::mutex> guard(g_daily_mtx);
        diet.log_portion(p_eff);
        json_anim["diet"] = diet.to_json();
        g_db->update_animal(json_anim);

        JsonValue uplink;
        JsonValue animal_entry;
        animal_entry["rfid"] = static_cast<unsigned int>(done.animal_id);
        animal_entry["diet"] = diet.to_json();
        uplink["animal"].append(animal_entry);
        uplink["actuator_id"] = static_cast<unsigned int>(src_id);
        g_mqtt->publish(MQTT_TOPIC_DIET_UDATA, uplink.dump());
        std::cout << "[feed] FEED_DONE logged for animal " << done.animal_id << std::endl;
    } catch (const std::exception& ex) {
        std::cerr << "[feed] FEED_DONE processing failed: " << ex.what() << std::endl;
    }
}

static void feed_thread()
{
    while (!g_stop) {
        NrfMessage msg;
        ProtoPacket pkt{};

        if (g_link.recv(PROTO_MSG_RFID_TAG, msg, FEED_THREAD_POLL_MS)) {
            if (packet_from_message(msg, pkt)) {
                ProtoRfidTag body{};
                if (Protocol::parse_rfid_tag(pkt, body)) {
                    handle_rfid_tag(msg.src_id, body);
                }
            }
            continue;
        }
        if (g_link.recv(PROTO_MSG_FEED_DONE, msg, 0)) {
            if (packet_from_message(msg, pkt)) {
                ProtoFeedDone body{};
                if (Protocol::parse_feed_done(pkt, body)) {
                    handle_feed_done(msg.src_id, body);
                }
            }
            continue;
        }
        if (g_link.recv(PROTO_MSG_WEIGHT, msg, 0)) {
            if (packet_from_message(msg, pkt)) {
                ProtoWeight body{};
                if (Protocol::parse_weight(pkt, body)) {
                    JsonValue uplink;
                    uplink["animal_id"] = static_cast<unsigned int>(body.animal_id);
                    uplink["weight_g"] = static_cast<unsigned int>(body.weight_g);
                    g_mqtt->publish(MQTT_TOPIC_DIET_UDATA, uplink.dump());
                }
            }
        }
    }
}

static void status_thread()
{
    while (!g_stop) {
        NrfMessage msg;
        if (g_link.recv(PROTO_MSG_STATUS, msg, STATUS_POLL_MS)) {
            std::lock_guard<std::mutex> lock(g_wa_mtx);
            g_wa_last_rx[msg.src_id] = std::time(nullptr);
            if (g_wa_conn_status[msg.src_id] != 0) {
                g_wa_conn_status[msg.src_id] = 0;
                JsonValue uplink;
                uplink["actuator_status"][std::to_string(msg.src_id)] = "online";
                g_mqtt->publish(MQTT_TOPIC_DIET_UASYNC, uplink.dump());
                std::cout << "[status] actuator " << static_cast<int>(msg.src_id) << " online" << std::endl;
            }
            send_ack(msg.src_id, PROTO_MSG_STATUS);
        }

        const std::time_t now = std::time(nullptr);
        std::lock_guard<std::mutex> lock(g_wa_mtx);
        for (auto& wa : g_wa_last_rx) {
            if (now > wa.second + WA_CONN_TIMEOUT_SEC && g_wa_conn_status[wa.first] == 0) {
                g_wa_conn_status[wa.first] = -1;
                JsonValue uplink;
                uplink["actuator_status"][std::to_string(wa.first)] = "offline";
                g_mqtt->publish(MQTT_TOPIC_DIET_UASYNC, uplink.dump());
                std::cout << "[status] actuator " << static_cast<int>(wa.first) << " offline" << std::endl;
            }
        }
    }
}

static bool is_daily_reset_window()
{
    std::time_t now = std::time(nullptr);
    std::tm local_tm{};
    localtime_r(&now, &local_tm);
    return local_tm.tm_hour == DAILY_RESET_HOUR && local_tm.tm_min >= DAILY_RESET_MIN;
}

static void daily_reset_thread()
{
    bool reset_done_today = false;
    while (!g_stop) {
        if (is_daily_reset_window()) {
            if (!reset_done_today) {
                std::cout << "[daily] running daily reset" << std::endl;
                JsonValue refresh;
                refresh["dailyrefresh"] = JsonValue();
                const auto diets = g_db->get_dietlist();
                for (uint32_t diet_id : diets) {
                    const auto animals = g_db->get_animallist(diet_id);
                    for (uint32_t animal_id : animals) {
                        try {
                            JsonValue json_anim = g_db->get_animal_json(animal_id);
                            DietEngine diet(json_anim["diet"]);
                            std::lock_guard<std::mutex> guard(g_daily_mtx);
                            diet.daily_reset();
                            json_anim["diet"] = diet.to_json();
                            g_db->update_animal(json_anim);
                            refresh["dailyrefresh"].append(static_cast<unsigned int>(animal_id));
                        } catch (const std::exception& ex) {
                            std::cerr << "[daily] reset failed for " << animal_id << ": " << ex.what() << std::endl;
                        }
                    }
                }
                g_mqtt->publish(MQTT_TOPIC_DIET_UASYNC, refresh.dump());
                reset_done_today = true;
            }
        } else {
            reset_done_today = false;
        }
        std::this_thread::sleep_for(std::chrono::seconds(30));
    }
}

int main(int argc, char** argv)
{
    (void)argc;
    (void)argv;

    std::signal(SIGINT, handle_signal);
    std::signal(SIGTERM, handle_signal);

    const std::string db_path = data_path();
    Database db(db_path);
    if (!db.ensure_seed()) {
        std::cerr << "Warning: could not seed database at " << db_path << std::endl;
    }
    g_db = &db;

    MqttClient mqtt(STATION_SN, MQTT_BROKER_DEFAULT, MQTT_BROKER_PORT_DEFAULT);
    g_mqtt = &mqtt;
    mqtt.connect_client();
    mqtt.subscribe(MQTT_TOPIC_DIET_DDATA);
    mqtt.subscribe(MQTT_TOPIC_DIET_DASYNC);

    if (g_link.init() != ENOERR) {
        std::cerr << "NRF init failed; continuing in stub mode" << std::endl;
    }
    g_link.start();

    std::thread feed_worker(feed_thread);
    std::thread status_worker(status_thread);
    std::thread daily_worker(daily_reset_thread);

    std::cout << "WiFeeder v2 host started (SN=" << STATION_SN << ", db=" << db_path << ")" << std::endl;

    while (!g_stop) {
        std::this_thread::sleep_for(std::chrono::milliseconds(200));
    }

    g_link.stop();
    if (feed_worker.joinable()) feed_worker.join();
    if (status_worker.joinable()) status_worker.join();
    if (daily_worker.joinable()) daily_worker.join();
    mqtt.disconnect_client();

    std::cout << "WiFeeder v2 host stopped" << std::endl;
    return 0;
}

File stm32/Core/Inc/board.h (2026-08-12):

/*
 * board.h - NUCLEO-L432KC pin map for WiFeeder v2 MVP (PCA9685 path)
 *
 * Authoritative wiring: wiring/CONNECTOR_MAP.md
 * One jumper per Nucleo header pin; PB6/PB7 = I2C1 only (not TIM16).
 */
#ifndef BOARD_H
#define BOARD_H

#include <stdint.h>

/* --- NRF24L01+ (bit-bang SPI) --- */
#define BOARD_NRF_SCK_PIN       5U   /* PA5 */
#define BOARD_NRF_MOSI_PIN      7U   /* PA7 */
#define BOARD_NRF_MISO_PIN      1U   /* PB1, pull-up input — PA6 is shorted */
#define BOARD_NRF_CSN_PIN       4U   /* PA4 */
#define BOARD_NRF_CE_PIN        0U   /* PB0 */

/* --- PCA9685 I2C1 (bit-bang) --- */
#define BOARD_I2C_SCL_PIN       6U   /* PB6 = D5 */
#define BOARD_I2C_SDA_PIN       7U   /* PB7 = D4 */
#define BOARD_PCA9685_ADDR      0x40U

/* PCA9685 PWM channels → IBT-2 (MVP: one motor) */
#define BOARD_PCA_CH_RPWM       0U   /* PWM0 → IBT RPWM */
#define BOARD_PCA_CH_LPWM       1U   /* PWM1 → IBT LPWM */

/* --- Motor2 TIM16 path deferred (pins reused by I2C) --- */
#if 0
#define BOARD_M2_PWM_PIN        6U   /* was PB6 TIM16_CH1 */
#define BOARD_M2_DIR_PIN        7U   /* was PB7 DIR */
#endif

/* --- Encoder 1 (TIM2 quadrature, 4×) --- */
#define BOARD_ENC1_A_PIN        0U   /* PA0 */
#define BOARD_ENC1_B_PIN        1U   /* PA1 */

/* --- RFID reader (USART2 RX) — deferred in MVP wiring --- */
#define BOARD_RFID_RX_PIN       3U   /* PA3 */

/* --- HX711 load cell — deferred in MVP wiring --- */
#define BOARD_HX711_DOUT_PIN    4U   /* PB4 */
#define BOARD_HX711_SCK_PIN     5U   /* PB5 */

/* --- Status LED --- */
#define BOARD_LED_PIN           3U   /* PB3 */

/* --- Timing / clocks --- */
#define BOARD_SYSCLK_HZ         4000000U
#define BOARD_ENCODER_PPR       600U  /* GTS06-OC-RA600A-2M physical P/R */
#define BOARD_ENCODER_COUNTS_PER_REV  (BOARD_ENCODER_PPR * 4U) /* TIM2 SMS=011 x4 */

/* MVP: RFID/HX711 not on Fritzing pack; gate optional features */
#ifndef WIFEEDER_MVP
#define WIFEEDER_MVP            1
#endif

/* Register-level GPIO helpers (match Core/Src/main.c style) */
#define BOARD_GPIOA_MODER       ((volatile uint32_t *)0x48000000U)
#define BOARD_GPIOA_ODR         ((volatile uint32_t *)0x48000014U)
#define BOARD_GPIOA_IDR         ((volatile uint32_t *)0x48000010U)
#define BOARD_GPIOA_AFRL        ((volatile uint32_t *)0x48000020U)
#define BOARD_GPIOA_AFRH        ((volatile uint32_t *)0x48000024U)

#define BOARD_GPIOB_MODER       ((volatile uint32_t *)0x48000400U)
#define BOARD_GPIOB_OTYPER      ((volatile uint32_t *)0x48000404U)
#define BOARD_GPIOB_ODR         ((volatile uint32_t *)0x48000414U)
#define BOARD_GPIOB_IDR         ((volatile uint32_t *)0x48000410U)
#define BOARD_GPIOB_PUPDR       ((volatile uint32_t *)0x4800040CU)
#define BOARD_GPIOB_AFRL        ((volatile uint32_t *)0x48000420U)

#define BOARD_RCC_AHB2ENR       ((volatile uint32_t *)0x4002104CU)
#define BOARD_RCC_APB1ENR1      ((volatile uint32_t *)0x40021058U)
#define BOARD_RCC_APB2ENR       ((volatile uint32_t *)0x40021060U)

void board_gpio_enable_clocks(void);
void board_delay(volatile uint32_t loops);
uint32_t board_millis(void);
void board_systick_init(void);
void board_led_init(void);
void board_led_set(int on);

#endif /* BOARD_H */

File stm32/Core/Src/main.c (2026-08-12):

/*
 * main.c - WiFeeder v2 production firmware entry
 *
 * Superloop calls wifeeder_poll(). FreeRTOS is vendored under
 * Middlewares/Third_Party/FreeRTOS for a later task split.
 * NRF bring-up probe lives in tests/03-nrf/.
 */
#include "board.h"
#include "wifeeder.h"

void SystemInit(void)
{
}

unsigned int SystemCoreClock = BOARD_SYSCLK_HZ;

int main(void)
{
    board_systick_init();
    board_led_init();
    board_led_set(1);

    wifeeder_init();

    for (;;) {
        wifeeder_poll();

        static uint32_t last_blink;
        uint32_t now = board_millis();
        if ((now - last_blink) >= 500U) {
            last_blink = now;
            static int led;
            led = !led;
            board_led_set(led);
        }
    }
}

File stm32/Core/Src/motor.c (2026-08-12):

/*
 * motor.c - IBT-2 motor control via PCA9685 PWM0/PWM1
 *
 * MVP: Motor1 only (RPWM=ch0, LPWM=ch1). EN tied to 3.3V in hardware.
 * Motor2 deferred (PB6/PB7 owned by I2C).
 */
#include "motor.h"
#include "board.h"
#include "pca9685.h"

static uint16_t gs_motor1_revs;
static uint8_t gs_motor1_duty = 70U;
static bool gs_motor1_forward = true;
static bool gs_pca_ok;

static void apply_m1(uint8_t duty_pct)
{
    if (!gs_pca_ok) {
        return;
    }
    if (duty_pct == 0U) {
        pca9685_set_duty(BOARD_PCA_CH_RPWM, 0);
        pca9685_set_duty(BOARD_PCA_CH_LPWM, 0);
        return;
    }
    if (gs_motor1_forward) {
        pca9685_set_duty(BOARD_PCA_CH_LPWM, 0);
        pca9685_set_duty(BOARD_PCA_CH_RPWM, duty_pct);
    } else {
        pca9685_set_duty(BOARD_PCA_CH_RPWM, 0);
        pca9685_set_duty(BOARD_PCA_CH_LPWM, duty_pct);
    }
}

void motor_init(void)
{
    gs_pca_ok = pca9685_init();
    motor_stop(MOTOR_1);
    motor_stop(MOTOR_2);
}

void motor_set_dir(motor_id_t motor_id, bool forward)
{
    if (motor_id != MOTOR_1) {
        return; /* Motor2 deferred */
    }
    gs_motor1_forward = forward;
}

void motor_set_duty(motor_id_t motor_id, uint8_t duty_pct)
{
    if (motor_id != MOTOR_1) {
        return;
    }
    gs_motor1_duty = duty_pct;
    apply_m1(duty_pct);
}

void motor_stop(motor_id_t motor_id)
{
    if (motor_id == MOTOR_1) {
        gs_motor1_revs = 0;
        apply_m1(0);
    }
    /* MOTOR_2: no-op (deferred) */
}

void motor_run(motor_id_t motor_id, uint16_t revs_target)
{
    if (motor_id != MOTOR_1) {
        return; /* Motor2 deferred until second PCA/IBT channel */
    }
    gs_motor1_revs = revs_target;
    motor_set_dir(MOTOR_1, true);
    apply_m1(gs_motor1_duty);
}

bool motor_pca_ok(void)
{
    return gs_pca_ok;
}

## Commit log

2026-08-12 Initial import of WiFeeder v2 sources and docs.
    Establish the repository baseline with firmware, Pi host, PCB, wiring, and documentation, excluding build artifacts.
    [01-power.fzz, 02-pca9685.fzz, 03-motor.fzz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]
2026-08-12 Stop tracking stm32/build2 CMake leftovers.
    Tighten .gitignore so numbered build directories are excluded from the tree.
2026-08-12 Promote GitHub CI, security, and contribution workflow to main (#1)
    * Add GitHub CI, security docs, and contribution workflow.
    Wire Actions CI/CodeQL, Dependabot, templates, and CODEOWNERS so main and develop can be protected and monitored.
    * Fix CI host build by using embedded min_json.
    System jsoncpp on Ubuntu breaks the host API (ambiguous operator[] / missing dump).
